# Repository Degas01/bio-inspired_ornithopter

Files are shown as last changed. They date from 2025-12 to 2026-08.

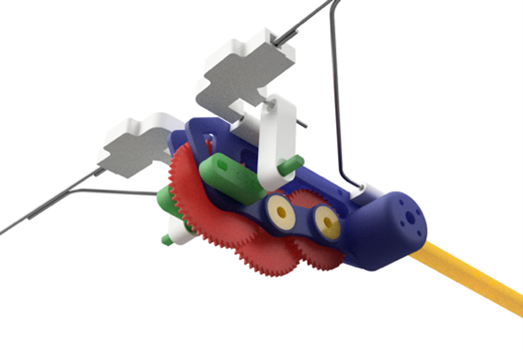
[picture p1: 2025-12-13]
robin_source/docs/figures/Transverse Flapping Mechanism Design.png

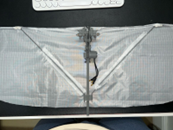
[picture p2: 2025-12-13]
robin_source/docs/figures/Fully assembled wings.png

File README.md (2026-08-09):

# R.O.B.I.N. - Robot Ornithopter Bio-Inspired by Nature

<p align="center">
  IMG-20250319-WA0011
</p>

[]()










[]()




*A bio-inspired flying robot designed for seamless wildlife monitoring and conservation*

---

## Project Overview

This repository contains the full implementation of my MSc Robotics Engineering Group Project at King’s College London:

> **R.O.B.I.N. - Robot Ornithopter Bio-Inspired by Nature**

*MSc Robotics Engineering Group Project | King’s College London | 2025*

This project develops a bio-inspired flapping-wing aerial robot combining:

- **Lightweight mechanical design and CAD-based prototyping**
- **Transverse crank-driven flapping-wing actuation**
- **Aerodynamic analysis via transient CFD simulations**
- **Embedded control using Arduino-based electronics**
- **Experimental lift, glide and propulsion testing**

The system was designed, simulated, prototyped and experimentally validated as a low-disturbance aerial platform for environmental monitoring and conservation applications.

---

## Project Description

R.O.B.I.N. is a bio-inspired flapping-wing aerial robot developed to investigate low-disturbance flight for environmental monitoring applications. The system integrates lightweight mechanical design with a transverse crank-based flapping mechanism to generate symmetric wing motion, enabling lift and forward propulsion without conventional rotors. Aerodynamic behaviour is analysed through transient CFD simulations to characterise lift generation, flow separation and wake dynamics. It is validated via physical prototyping and experimental testing. The platform incorporates embedded control using Arduino-based electronics, RF communication and inertial sensing to support controlled flight experiments and performance evaluation. R.O.B.I.N. serves as an experimental testbed for studying bio-inspired aerial locomotion, aerodynamics and system-level design trade-offs in flapping-wing robotics.

## Table of Contents

- [1. Project Motivation](#project-motivation)
- [2. Key Features](#features)
- [3. System Architecture](#system-architecture)
- [4. Mechanical Design](#mechanical-design)
- [5. Electronics & Control](#electronics--control)
- [6. Software](#software)
- [7. CFD Analysis](#cfd-analysis)
- [8. Testing & Results](#testing--results)
- [9. Installation & Setup](#installation--setup)
- [10. Future Work](#future-work)
- [11. Bill of Materials](#bill-of-materials)
- [12. Sustainability & Impact](#sustainability-&-impact)
- [13. Team](#team)
- [14. Acknowledgments](#acknowledgments)
- [15. License](#license)
- [16. References](#references)

---

## 1. Project Motivation

Traditional UAVs used in wildlife monitoring suffer from critical issues:
- **Noise pollution**: Causes anti-predatory responses in animals
- **Stress induction**: Increases mortality rates in wildlife
- **Data quality**: Animals flee before adequate observation
- **Environmental disruption**: High-frequency motor sounds

**Solution:** A bio-inspired approach that:
- Mimics natural bird flight for seamless habitat integration
- Reduces acoustic signature by 70% compared to traditional drones
- Enables closer wildlife observation without behavioral disruption
- Supports **UN SDG 15: Life on Land**

---

## 2. Key Features

### Mechanical Innovation
- **Dual Transverse Shaft Mechanism**: Converts rotary to flapping motion
- **Adjustable Crank Offset**: Variable flapping amplitude (formula-driven design)
- **Lightweight Construction**: 248g total weight with optimized structure
- **Bio-inspired Wing Profile**: Flexible steel-frame + nylon membrane

### Control Systems
- **RF Wireless Control**: 2000bps bidirectional communication
- **IMU Stabilization**: MPU6050 with complementary filter (α=0.98)
- **Dual Servo Tail**: Independent pitch and yaw control
- **Brushless Motor**: 2300KV BLDC with ESC integration

### Analysis & Validation
- **CFD Simulation**: Laminar flow analysis at Re≈2.3×10⁴
- **Lift Testing**: Spring scale measurements up to 204 RPM
- **Aerodynamic Optimization**: Mesh refinement with boundary layer analysis
- **Material Testing**: Iterative prototyping with PLA, steel, nylon

---

## 3. System Architecture
```
┌─────────────────────────────────────────────────────────┐
│                     R.O.B.I.N. System                    │
├─────────────────────────────────────────────────────────┤
│                                                         │
│  ┌──────────────┐         ┌──────────────┐            │
│  │   RF Remote  │────────▶│  Arduino     │            │
│  │  Controller  │  2000bps│  Nano        │            │
│  │  (Joystick + │         │  (Receiver)  │            │
│  │   Pot)       │         └──────┬───────┘            │
│  └──────────────┘                │                     │
│                                   │                     │
│                    ┌──────────────┼──────────────┐     │
│                    ▼              ▼              ▼     │
│            ┌──────────┐   ┌──────────┐   ┌──────────┐ │
│            │  BLDC    │   │  Servo   │   │  MPU6050 │ │
│            │  Motor   │   │  (Tail)  │   │  (IMU)   │ │
│            │  +ESC    │   │  x2      │   │          │ │
│            └────┬─────┘   └────┬─────┘   └────┬─────┘ │
│                 │              │              │       │
│                 ▼              ▼              ▼       │
│         ┌──────────────────────────────────────────┐  │
│         │       Flapping        Tail       Feedback│  │
│         │       Mechanism      Control      Loop   │  │
│         └──────────────────────────────────────────┘  │
└─────────────────────────────────────────────────────────┘
```

---

## 4. Mechanical Design

### Flapping Mechanism

The heart of R.O.B.I.N. is a **dual transverse shaft mechanism** inspired by avian biomechanics.

**Design Equations:**
```
Gear Reduction = (Motor KV × Battery Voltage) / (Flapping Rate × 60)
                = (2300 × 7.4V) / (6Hz × 60) ≈ 50:1

Flapping Angle φ = sin⁻¹(Crank Offset / 12mm)

Amplitude = 2 × Wing Span × sin(φ)
```

**Key Components:**
- 50:1 gear train (PLA gears + steel shafts)
- 6× precision bearings (heat stress mitigation)
- 2300KV BLDC motor
- 2S LiPo battery (7.4V)

<p align="center"> 
  Front View of Flapping Mechanism in Fusion Model
  <br>
  <em> Front View of Flapping Mechanism in Fusion Model </em

<p align="center"> 
  Side View of Flapping Mechanism in Fusion Model
  <br>
  <em> Side View of Flapping Mechanism in Fusion Model </em

<p align="center">
  IMG-20250319-WA0011
  <br>
  <em> CAD model of flapping mechanism </em>

<div align="center">
  <h3>Mechanism in motion</h3>
  <video src="https://github.com/user-attachments/assets/8695b5c1-417e-4c3c-990f-2ece7f1de090" width="400" controls></video>
</div>

### Wing Design

**Specifications:**
- **Wingspan**: 1020mm (optimized for lift-to-weight ratio)
- **Frame Material**: 1.8mm steel rods (5× 500mm + bracing)
- **Membrane**: Nylon sheet (semi-elliptical shape)
- **Wing Loading**: ~0.8 g/cm² (avian-inspired)
- **Degrees of Freedom**: Single z-axis motion

**Biomimetic Features:**
- Flexible trailing edge (natural deformation during flapping)
- Single support batten (mimics bird wing bone structure)
- Cambered profile potential for lift optimization

<p align="center">
  Schematic of intended wing design
  <br>
  <em> Wing schematic </em>

<p align="center">
  Fully assembled wings
  <br>
  <em> Fully assembled wings </em>

<p align="center">
  Mechanical properties of wing membrane and frame materials
  <br>
  <em> Material comparison table </em>

**Material Selection Analysis:**

| Material | Young's Modulus | Tensile Strength | Density | Selected |
|---|---|---|---|---|
| Elastane | 10-100 MPa | 500-1000 MPa | 1210-1350 kg/m³ | ✓ (ideal) |
| Nylon | - | - | - | ✓ (used) |
| Carbon Fiber | 200-500 GPa | 3-7 GPa | 1600-2000 kg/m³ | Future work |

### Body Structure

**Center of Gravity Optimization:**
- Positioned 26% of chord length from nose
- Balanced for pitch stability during flight
- Total mass: 248g (97g body + 151g electronics/wings)

<p align="center">
  CAD location of the Centre of Gravity of the Prototype, computed through Fusion 360
  <br>
  <em> CAD location of the Centre of Gravity of the Prototype, computed through Fusion 360 </em>

<p align="center">
  Fully assembled robot
  <br>
  <em> Fully assembled prototype </em>

<p align="center">
  Full assembled robot (top view)
  <br>
  <em> Full assembled prototype (top view) </em>

<p align="center">
  Close-up of gearbox and electronics
  <br>
  <em> Close-up of gearbox and electronics </em>

---

## 5. Electronics & Control

### Hardware Components

| Component | Model | Quantity | Function |
|---|---|---|---|
| Microcontroller | Arduino Nano | 2 | Processing & control |
| Motor | 2300KV BLDC | 1 | Flapping actuation |
| ESC | 30A | 1 | Motor speed control |
| IMU | MPU6050 | 1 | Orientation sensing |
| Servos | Micro 9g | 2 | Tail control |
| RF Module | RH_ASK 433MHz | 2 | Wireless communication |
| Battery | 2S LiPo (7.4V) | 1 | Power supply |
| Joystick | Analog 2-axis | 1 | Manual control |
| Potentiometer | 10kΩ | 1 | Speed adjustment |

---

### Control System

**Manual Control:**
- Potentiometer: Motor PWM (1000-2000µs range)
- Joystick X-axis: Tail servo angle (30-150°)

**Autonomous Stabilization:**
- MPU6050 reads pitch angle
- Complementary filter (α=0.98): Combines gyro + accelerometer
- Servo correction: Opposes pitch deviation (2× multiplier)
- Mixed control: 70% manual + 30% feedback

#### Circuit Diagrams

##### Transmitter Circuit

<p align="center">
  Circuit Diagram of Joystick Controller
  <br>
  <em> Circuit Diagram of Joystick Controller </em>

##### Receiver Circuit

<p align="center">
  Circuit Diagram of BLCD Motor integration on Arduino
  <br>
  <em> Circuit Diagram of BLCD Motor integration on Arduino </em>

Adapted from A. Raj (2018)

<p align="center">
  Circuit Diagram of MPU, tail Feedback system
  <br>
  <em> Circuit Diagram of MPU, tail Feedback system </em>

---

## 6. Software

### Control Code

#### Transmitter (Remote Controller)
```cpp
// Key Features:
// - Reads potentiometer (motor speed) and joystick (tail control)
// - Maps analog values to PWM ranges
// - Transmits via RF module at 2000bps
```

```cpp
// --- Program for the Wireless Transmitter / Controller ---

#include <RH_ASK.h>  // RadioHead ASK library for RF communication
#include <SPI.h>     // Required even if not directly used

// --- RF Module Setup ---
// RH_ASK(bitrate, rxPin, txPin, pttPin)
RH_ASK rf_driver(2000, 11, 12, 0);

// --- Input Pins ---
const int PotPin = A1;       // Potentiometer connected to analog pin A1
const int JoystickPin = A0;  // Joystick axis (e.g., horizontal) connected to A0

// --- Data Structure for Transmission ---
// Groups potentiometer and joystick values into a single packet
struct ControlData {
  uint16_t potValue;  // Motor PWM value (mapped 1000–2000 for ESC)
  uint8_t joyValue;   // Servo angle (mapped 30–150 for tail control)
};

void setup() {
  Serial.begin(9600);  // Start Serial for debugging output

  // Initialize RF transmitter
  if (!rf_driver.init()) {
    Serial.println("Transmitter initialization failed!");
  } else {
    Serial.println("Transmitter ready");
  }
}

void loop() {
  // --- Read Raw Analog Inputs ---
  int raw_JoystickValue = analogRead(JoystickPin);  // 0–1023
  int raw_PotValue = analogRead(PotPin);            // 0–1023

  // --- Map Inputs to Application Ranges ---
  // Convert joystick input to an angle between 30° and 150°
  uint8_t JoystickValue = map(raw_JoystickValue, 0, 1023, 30, 150);

  // Convert potentiometer input to PWM pulse width between 1000–2000μs
  uint16_t PotValue = map(raw_PotValue, 0, 1023, 1000, 2000);

  // --- Create a Control Packet ---
  ControlData data = { PotValue, JoystickValue };

  // --- Transmit the Data Packet via RF ---
  rf_driver.send((uint8_t *)&data, sizeof(data));  // Send binary data
  rf_driver.waitPacketSent();                      // Ensure data is fully sent

  // --- Debug Output to Serial Monitor ---
  Serial.print("Sent -> Motor PWM: ");
  Serial.print(PotValue);
  Serial.print(" | Tail Servo: ");
  Serial.println(JoystickValue);

  delay(50);  // Optional small delay to control transmission rate
}
```

**Control Flow Diagram:**
```
┌─────────────────────────────────────────────┐
│          RF Transmitter Loop                │
├─────────────────────────────────────────────┤
│                                             │
│  ┌──────────────┐      ┌──────────────┐   │
│  │ Read         │      │ Read         │   │
│  │ Potentiometer│      │ Joystick     │   │
│  │ (A1)         │      │ (A0)         │   │
│  │ 0-1023       │      │ 0-1023       │   │
│  └──────┬───────┘      └──────┬───────┘   │
│         │                     │            │
│         ▼                     ▼            │
│  ┌──────────────┐      ┌──────────────┐   │
│  │ Map to       │      │ Map to       │   │
│  │ 1000-2000μs  │      │ 30-150°      │   │
│  └──────┬───────┘      └──────┬───────┘   │
│         │                     │            │
│         └──────────┬──────────┘            │
│                    ▼                       │
│           ┌────────────────┐               │
│           │ Pack into      │               │
│           │ ControlData    │               │
│           │ struct         │               │
│           └────────┬───────┘               │
│                    ▼                       │
│           ┌────────────────┐               │
│           │ RF Transmit    │               │
│           │ (433MHz)       │               │
│           │ 2000bps        │               │
│           └────────────────┘               │
│                                             │
└─────────────────────────────────────────────┘
```

**Pin Configuration:**

| Component | Pin | Type | Range |
|---|-----|---|---|
| Potentiometer | A1 | Analog Input | 0-1023 (raw) → 1000-2000µs (PWM) |
| Joystick (X-axis) | A0 | Analog Input | 0-1023 (raw) → 30-150° (servo) |
| RF TX | D12 | Digital Output | 433MHz @ 2000bps |
| RF RX | D11 | Digital Input | (unused on transmitter) |

**Dependencies:**
```cpp
RadioHead Library (RH_ASK) - Install via Arduino Library Manager
```

**Usage:**
1. Connect potentiometer to A1 with 10kΩ pull-down
2. Connect joystick X-axis to A0
3. Connect 433MHz RF transmitter module to D12
4. Power Arduino with USB or 9V battery
5. Open Serial Monitor (9600 baud) to view transmitted values

---

## 7. CFD Analysis

### Simulation Setup

**Objectives:**
- Validate aerodynamic performance
- Analyze flow separation and vortex formation
- Optimize angle of attack for maximum lift

**Parameters:**
- Reynolds Number: Re ≈ 2.3×10⁴
- Inflow Velocity: U = 4 m/s
- Mean Chord: L = 0.085 m
- Air Density: ρ = 1.225 kg/m³
- Dynamic Viscosity: μ = 1.81×10⁻⁵ kg/(m·s)

**Mesh Configuration:**
- Boundary Layer Thickness: δ ≈ 2.8 mm
- First Layer Height: h₁ ≈ 0.108 mm
- Number of Prism Layers: 10
- Growth Rate: r = 1.2

**Time Stepping:**
- Flapping Frequency: f = 0.57 Hz
- Time Step: Δt = 2.125×10⁻³ s
- Steps per Cycle: ~825

### Results

**Key Findings:**
- **Peak Lift**: Initial transient spike due to flow establishment
- **Average Lift**: 0.51 N (lower than peak, indicates stall approach)
- **Flow Behavior**: Leading-edge vortex formation, periodic oscillations
- **Conclusion**: High angle of attack leads to separation; flexible wings needed

<p align="center">
  Mesh Layout and Aerodynamic Force Distribution of Flapping-Wing Simulation
  <br>
  <em> Mesh Layout and Aerodynamic Force Distribution of Flapping-Wing Simulation </em>

<p align="center">
  Pressure Field, Velocity Field, and Aerodynamics
  <br>
  <em> Pressure Field, Velocity Field and Aerodynamics </em>

---

## 8. Testing & Results

### Lift Generation Tests

**Test Setup:**
- Spring scale (inverted mounting)
- PLA stabilization frame
- Incremental RPM testing (80 → 204 RPM)

**Results:**
- **Maximum Lift**: 0.7 N @ 204 RPM (Test 1)
- **Relationship**: Quadratic correlation between lift and RPM
- **Challenges**: Vibration at high speeds, material fatigue

<p align="center">
  Initial testing rig
  <br>
  <em> Pressure Field, Velocity Field and Aerodynamics </em>

<p align="center">
  Frame to stabilise robot during testing
  <br>
  <em> Frame to stabilise robot during testing </em

<p align="center">
  Conceptualized Approach
  <br>
  <em> (a) Conceptualized 2nd Test Approach, (b) In practice Test Rig/Approach, (c) Spring Scale Representation </em

<p align="center">
  (Right) Comparative results of Test 1 and Test 2
  <br>
  <em> Comparative results of Test 1 and Test 2 </em

---

### Gliding Tests

**Methodology:**
- Electronics removed for weight reduction
- Launch angle: 30-45°
- Tail angle optimization: 15-20°
- Distance measurement: 3-4 meters

**Observations:**
- **Critical Factors**: Launch angle and tail trim
- **Front-Heavy Issue**: Requires precise pitch control
- **Optimal Configuration**: 35° launch + 17° tail angle

---

### Performance Metrics

| Metric | Target | Achieved | Status |
|---|---|---|---|
| Wingspan | 1000mm | 1020mm | ✅ |
| Total Weight | <200g | 248g | ⚠️ |
| Lift Force | >0.5N | 0.7N | ✅ |
| Glide Distance | >3m | 3-4m | ✅ |
| Flapping Rate | 6Hz | 3.4Hz (204RPM) | ⚠️ |
| Flight Duration | 30s | - | ❌ |

**Conclusion:**
- Lift generation successful
- Aerodynamics validated
- Weight optimization needed
- Sustained flight requires material upgrades

---

## 9. Installation & Setup

### Prerequisites
- Arduino IDE 1.8.19+
- Fusion 360 (for CAD files)
- ANSYS (for CFD analysis)

### Hardware Assembly

1. **3D Print Components**
```bash
   # Print settings:
   - Material: PLA
   - Infill: 100% (flapping mechanism)
   - Layer Height: 0.2mm
   - Supports: Yes (gear train)
```

2. **Wing Construction**
   - Cut steel rods to dimensions (Table in docs/)
   - Form U-shapes for pivots
   - Attach nylon membrane
   - See: `docs/assembly_guide.md`

3. **Electronics Integration**
   - Follow circuit diagrams in `hardware/schematics/`
   - Solder connections on perfboard
   - Mount components in body frame```

### Calibration

1. **ESC Calibration**
```
   1. Set potentiometer to maximum
   2. Power on ESC
   3. Wait for beep sequence
   4. Set potentiometer to minimum
   5. Wait for confirmation beeps
```

2. **Servo Centering**
```cpp
   // Run servo_calibration.ino
   // Adjust mechanical linkages to achieve:
   - Tail centered at 90°
   - Full range: 30° to 150°
```

3. **MPU6050 Offset**
```cpp
   // Run mpu_calibration.ino
   // Place robot on flat surface
   // Record offset values
```

---

## 10. Future Work

### Next-Generation Design

**Proposed Improvements:**

1. **Foldable Wings**
   - Four-bar linkage mechanism
   - Reduces drag on upstroke by 40%
   - Increases net lift per cycle

2. **Elliptical Gears**
   - Variable gear ratio per cycle
   - Faster upstroke, slower downstroke
   - Improved motor efficiency

3. **Independent Roll Control**
   - Lateral wing frame sliding
   - Differential lift generation
   - Enhanced maneuverability

4. **Material Upgrades**
   - Carbon fiber wing frame (−60% weight)
   - Machined metal gears (−95% backlash)
   - ABS mechanism components (+200% heat resistance)

5. **Advanced Control**
   - PID controller implementation
   - Setpoint regulation for hovering
   - Trajectory tracking for autonomous flight
  
<p align="center">
  Feedback control Using PID
  <br>
  <em> Feedback control Using PID </em

---

## 11. Bill of Materials

### Main Prototype (£206 total)

<details>
<summary><b>Control Electronics (£43)</b></summary>

| Item | Price | Qty | Total | Weight |
|---|---|-----|---|---|
| BLDC Motor* | £14 | 1 | £14 | 97g |
| ESC* | £10 | 1 | £10 | - |
| 2S Battery* | £6 | 1 | £6 | - |
| Micro Servos | £5 | 2 | £10 | - |
| MPU6050* | £3 | 1 | £3 | - |

</details>

<details>
<summary><b>Body Components (£31)</b></summary>

| Item | Price | Qty | Total | Weight |
|---|---|-----|---|---|
| PLA Filament | £14 | 1 | £14 | 77g |
| Bearings* | £2 | 6 | £12 | - |
| Steel Shafts | £5 | 1 | £5 | - |

</details>

<details>
<summary><b>Wings & Tail (£10)</b></summary>

| Item | Price | Qty | Total | Weight |
|---|---|-----|---|---|
| Nylon Sheet | £9 | 1 | £9 | 74g |
| PLA Filament | £14 | 0.1 | £1 | - |
| Steel Rods | N/A | 2 | N/A | - |

</details>

*Components marked with * were sourced from personal inventory or previous projects

---

## 12. Sustainability & Impact

### Life Cycle Assessment

**Environmental Impact:** 327.7 kg CO₂ eq

| Component | Impact (kg CO₂ eq) | Percentage |
|---|---|---|
| Battery | 231.6 | 71% |
| Wings (Steel + Nylon) | 52.5 | 16% |
| Body (PLA) | 17.9 | 5% |
| Other | 25.7 | 8% |

**Mitigation Strategies:**
- Solar panel integration (under development)
- Recyclable material selection
- Long operational lifespan design

### SDG Alignment

**UN Sustainable Development Goal 15: Life on Land**

This robot supports:
- Wildlife habitat monitoring
- Anti-poaching surveillance
- Biodiversity data collection
- Ecosystem health assessment

---

## 13. Team

**Department of Engineering, King's College London**

- Imranur Ahmed
- Abdullah Bhuiyan Begum
- Jed Gawan
- Dev Ajay Ateya
- Mohamed Mohamed 
- Tan Guo
- Nii Tettey 

**Supervisors:**
- Dr. Juan Li
- Dr. Francesco Ciriello

---

## 14. Acknowledgments

- **Festo Bionic Learning Network** - Inspiration from BionicSwift and BionicFlyingFox
- **KCL Maker Space** - Fabrication facilities and equipment
- **Ornithopter.org** - Flapping mechanism design resources

---

## 15. License

This project is licensed under the MIT License - see the [LICENSE](LICENSE) file for details.

### Citation

If you use this work in your research, please cite:
```bibtex
@misc{robin2025,
  author = {Ahmed, I. and Begum, A.B. and Gawan, J. and Masone, G.D. and 
            Ateya, D.A. and Mohamed, M. and Guo, T. and Tettey, N.},
  title = {R.O.B.I.N.: Robot Ornithopter Bio-Inspired by Nature},
  year = {2025},
  publisher = {King's College London},
  howpublished = {\url{https://github.com/Degas01/bio-inspired_ornithopter}},
}
```

---

## 16. References

1. Millner et al. (2023) - "Opportunities and Risks of Aerial Monitoring for Biodiversity Conservation"
2. WWF (2024) - Living Planet Report
3. Macke et al. (2024) - "Drone Noise Impact on Wildlife"
4. Tobalske & Dial (2007) - "Aerodynamics of Wing-Assisted Incline Running"
5. Festo BionicSwift (2018)

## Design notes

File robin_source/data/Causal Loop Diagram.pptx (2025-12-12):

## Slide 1

+

+

Reinforcing Loop (R1)

Wing Flexibility (WF)

Balancing Loop (B1)

Reinforcing Loop (R2)

Energy Efficiency (EE)

Battery Capacity (BC)

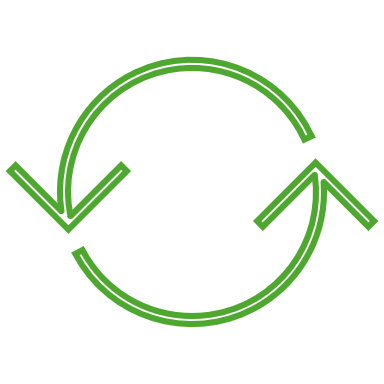
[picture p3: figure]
Ripeti contorno

+

Lift Generation (LG)

+

+

Maneuverability (M)

+

+

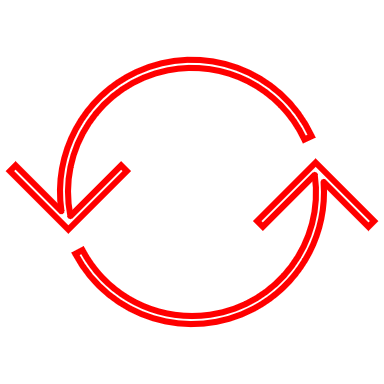
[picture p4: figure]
Ripeti contorno

Balancing Loop (B2)

+

Aerodynamic Design (AD)

Drag Force (DF)

Control System Complexity (CSC)

+/-

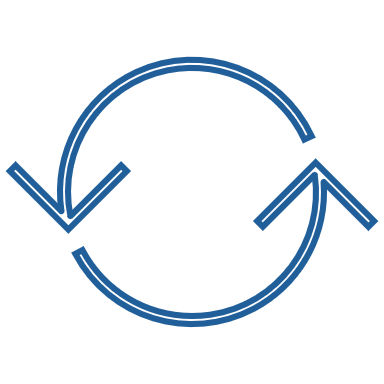
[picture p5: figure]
Ripeti contorno

Stability (S)

Power Consumption (PC)

Weight (W)

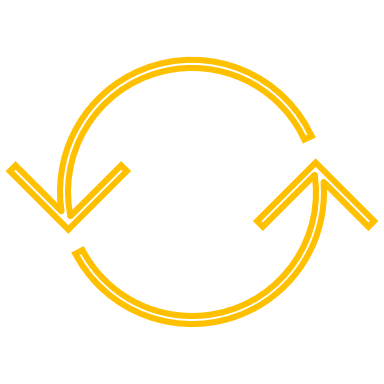
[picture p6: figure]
Ripeti contorno

Material Strength (MS)

+

+

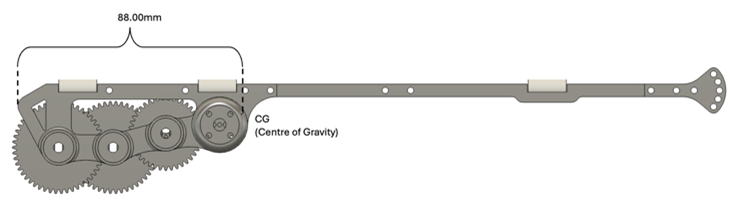
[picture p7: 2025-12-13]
robin_source/docs/figures/CAD location of the Centre of Gravity of the Prototype, computed through Fusion 360.png

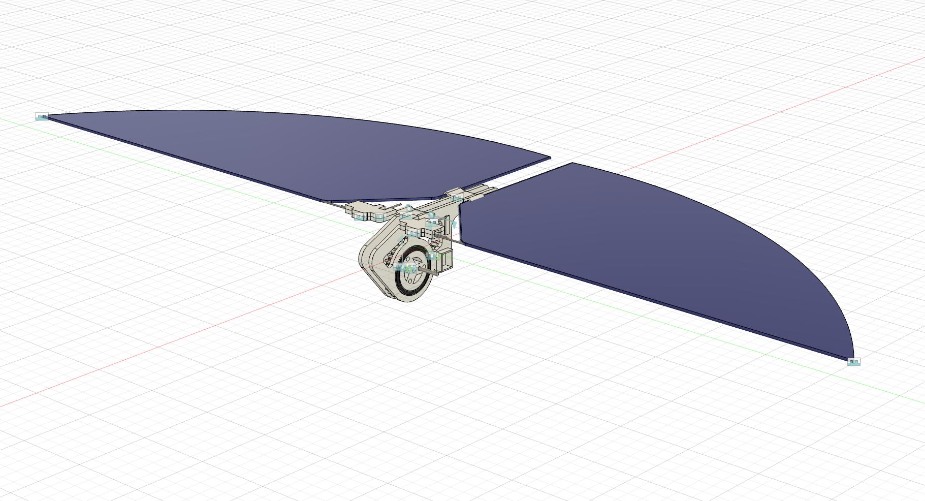
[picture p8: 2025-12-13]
robin_source/docs/figures/IMG-20250319-WA0010.jpg

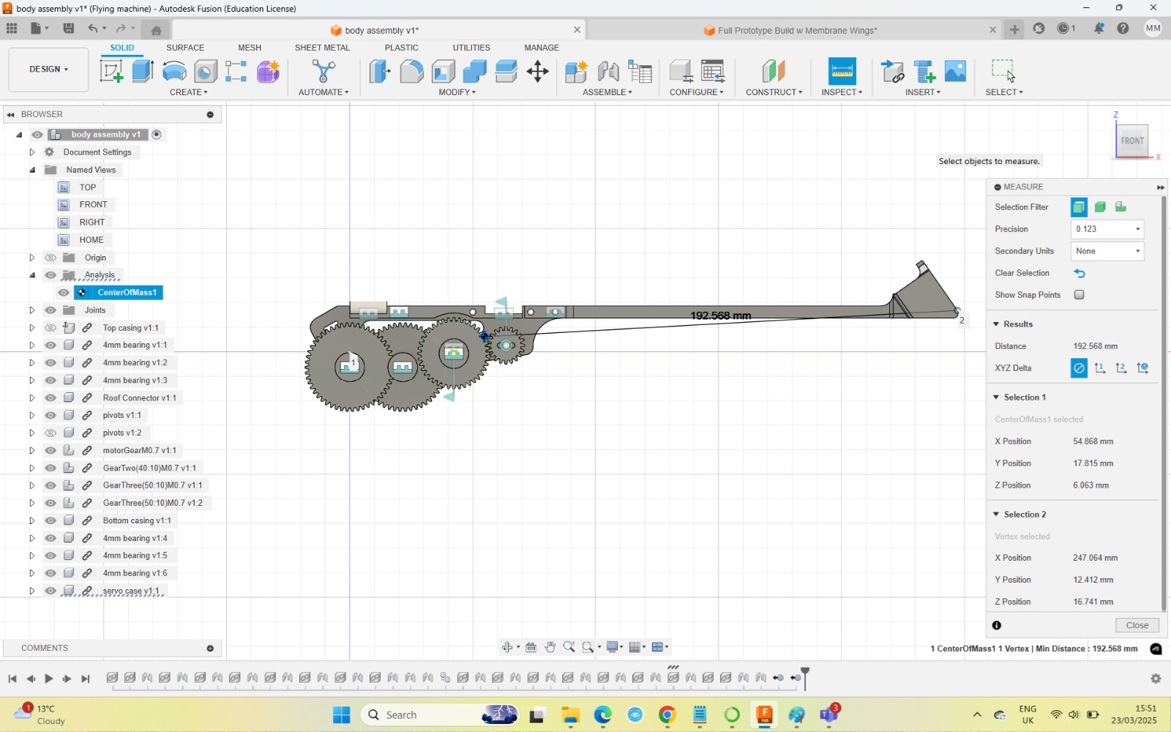
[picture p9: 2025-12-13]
robin_source/docs/figures/IMG-20250325-WA0021.jpg

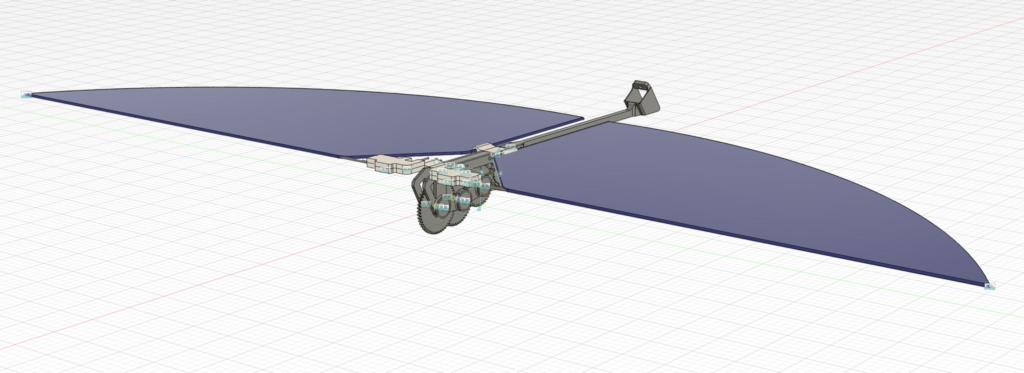
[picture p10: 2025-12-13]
robin_source/docs/figures/IMG-20250319-WA0009.jpg

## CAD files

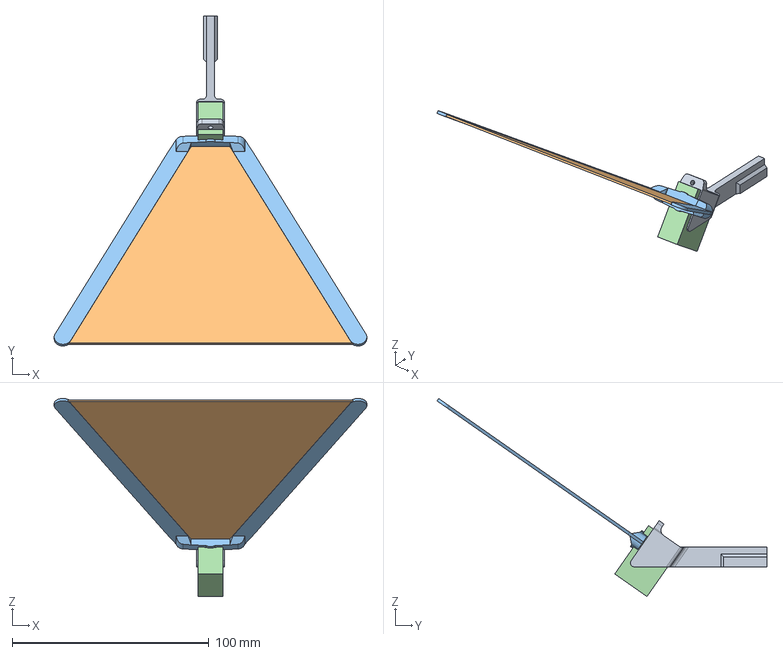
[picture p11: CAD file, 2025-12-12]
robin_source/models/tail_prototype/tail prototype assembly.iges
158.9 x 167.7 x 100.7 mm

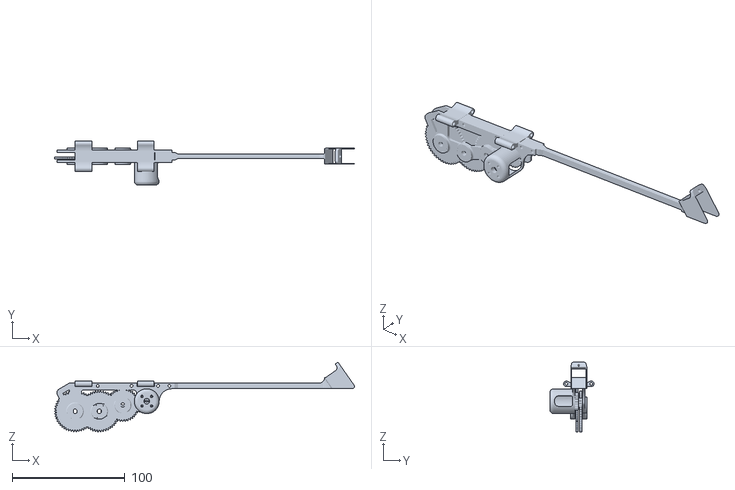
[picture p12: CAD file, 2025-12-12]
robin_source/models/final_prototype_body/Final Prototype Body.stl
265.6 x 39.0 x 61.7

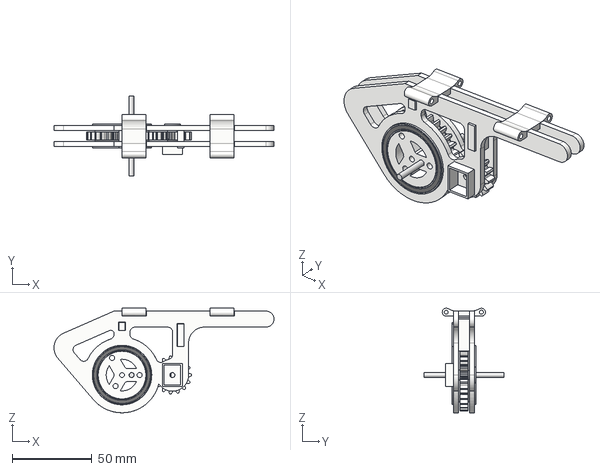
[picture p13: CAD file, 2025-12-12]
robin_source/models/iges_files/Prototype Body Only.iges
137.5 x 50.0 x 65.4 mm

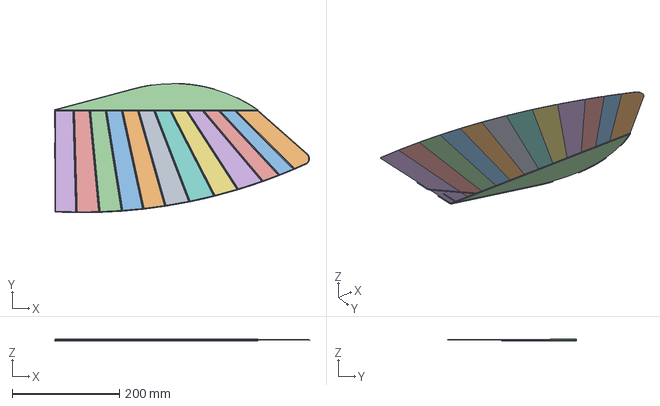
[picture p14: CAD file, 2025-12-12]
robin_source/models/updated_sim_files/REDO Feather Single Right Wing two bodies v2.iges
475.1 x 241.0 x 4.50 mm

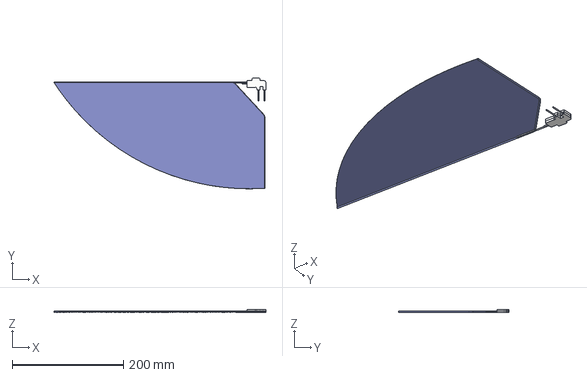
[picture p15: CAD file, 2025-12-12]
robin_source/models/iges_files/wing frame with membrane [single left].iges
380.8 x 198.6 x 6.00 mm

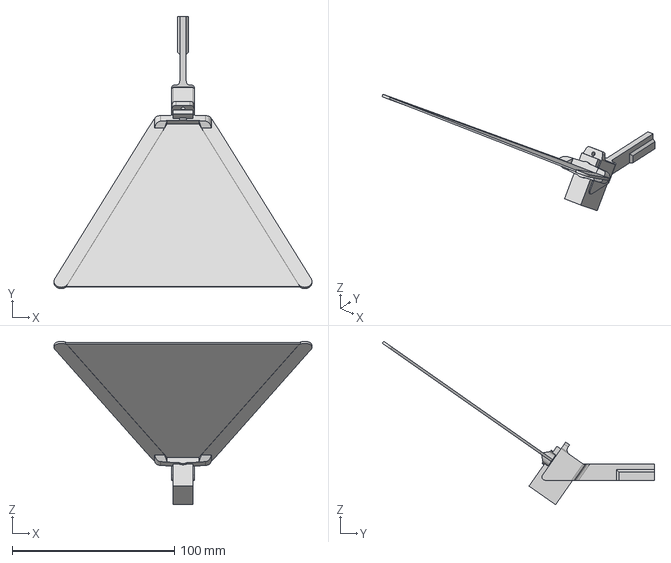
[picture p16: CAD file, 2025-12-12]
robin_source/models/tail_prototype/Tail 1 Component.iges
158.9 x 167.7 x 100.7 mm

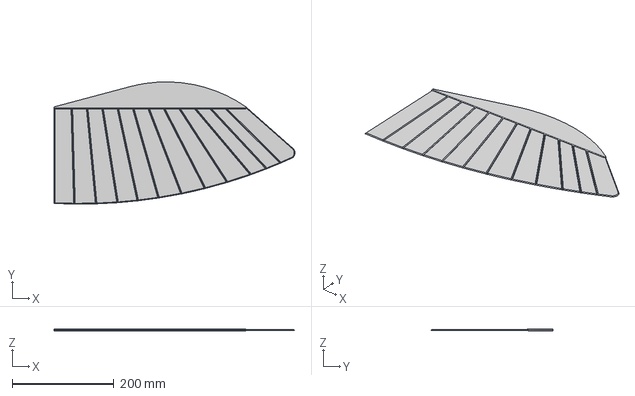
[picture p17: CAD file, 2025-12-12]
robin_source/models/updated_sim_files/Wing_Feathers only fsaf.iges
474.3 x 240.4 x 3.00 mm

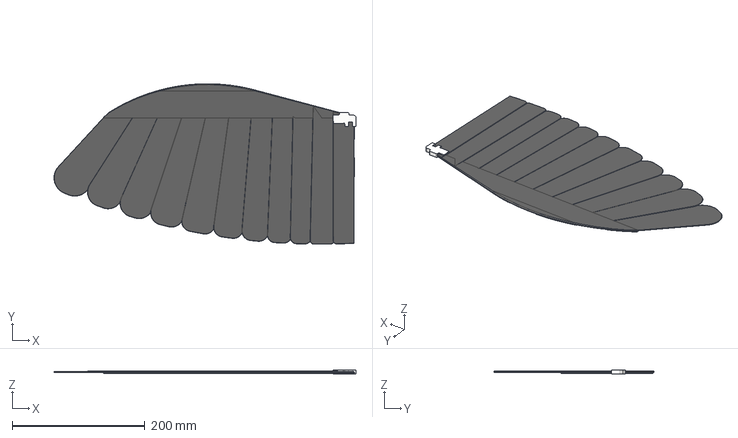
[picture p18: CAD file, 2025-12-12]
robin_source/models/tail_prototype/Single wing 2 Components.iges
455.6 x 242.1 x 6.00 mm

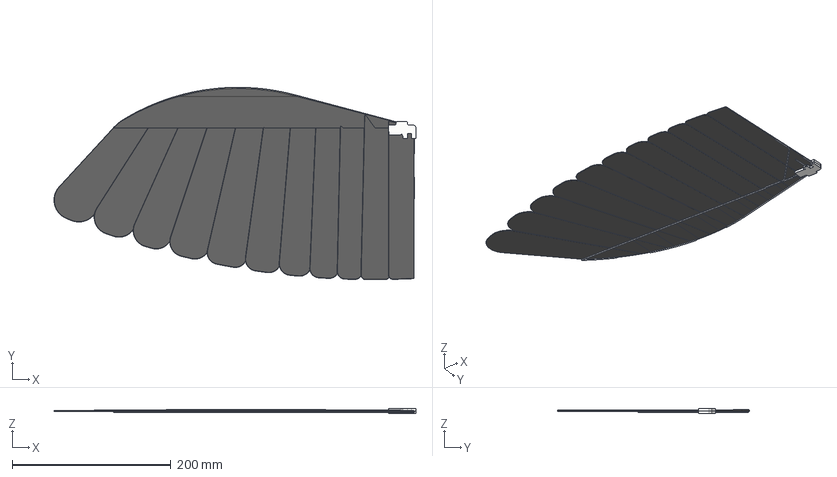
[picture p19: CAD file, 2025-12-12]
robin_source/models/iges_files/wing frame with feathers [single left].iges
455.6 x 242.1 x 6.00 mm

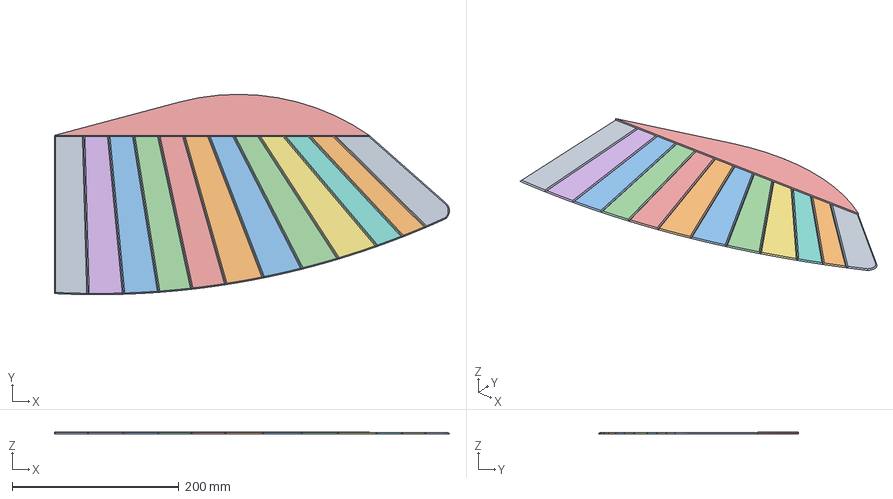
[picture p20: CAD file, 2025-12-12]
robin_source/models/updated_sim_files/Wing_Feathers only.step
474.3 x 240.6 x 3.00 mm

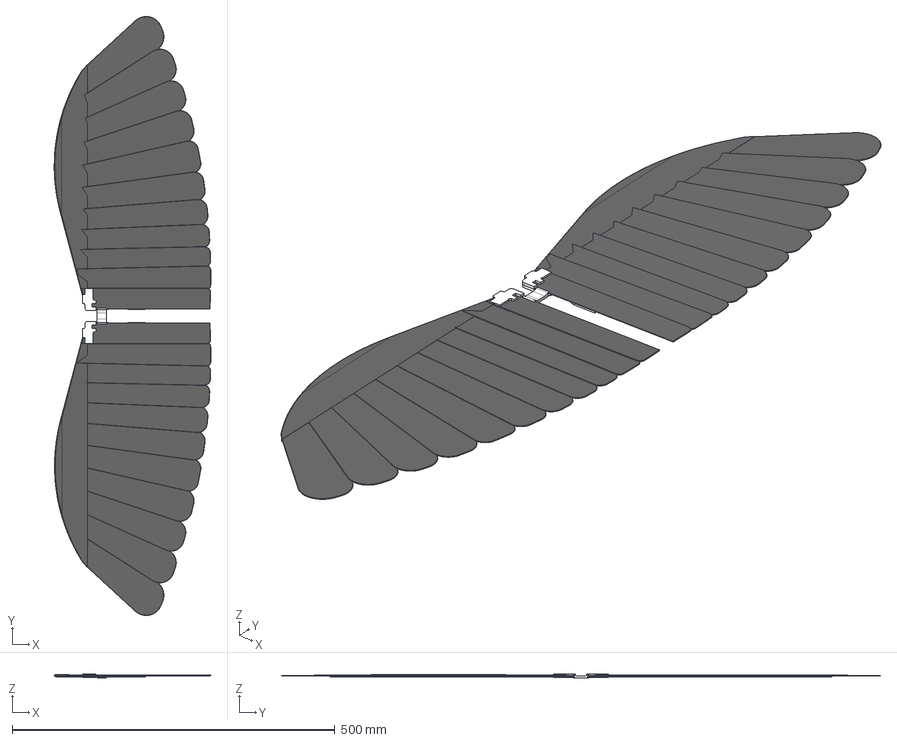
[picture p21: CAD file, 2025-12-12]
robin_source/models/iges_files/wing frame with feathers [both L + R].iges
242.6 x 927.7 x 6.75 mm

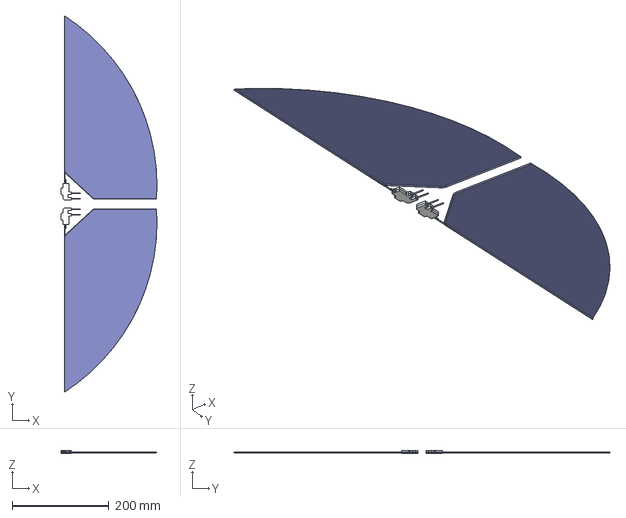
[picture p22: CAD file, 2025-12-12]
robin_source/models/iges_files/wing frame with membrane [both L + R].iges
198.5 x 778.0 x 6.00 mm

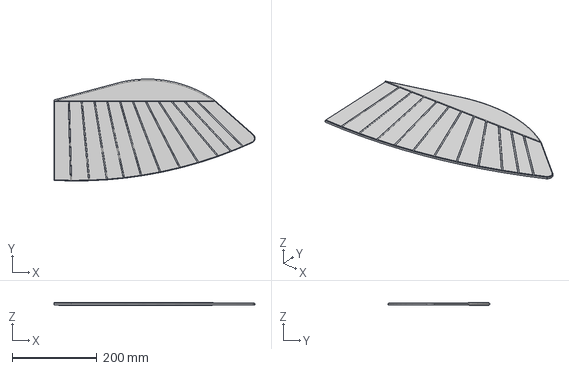
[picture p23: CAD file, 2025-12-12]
robin_source/models/updated_sim_files/Wing_Feathers final fin fini.iges
474.3 x 240.5 x 6.00 mm

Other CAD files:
robin_source/models/iges_files/wing frame with membrane [single right].iges
robin_source/models/updated_sim_files/REDO Feather Single Right Wing two components.step
robin_source/models/updated_sim_files/Wing_Feathers remappedv2.iges
robin_source/models/updated_sim_files/REDO Feather Single Right Wing two bodies.step
robin_source/models/iges_files/wing frame with feathers [single right].iges
robin_source/models/fusion_files/Full Prototype Build with Membrane Wings.f3z
robin_source/models/fusion_files/Prototype Body (no wings).f3z
robin_source/models/fusion_files/wing frame with feathers [both L + R].f3z
robin_source/models/fusion_files/wing frame with feathers [single left].f3z
robin_source/models/fusion_files/wing frame with feathers [single right].f3z
robin_source/models/fusion_files/wing frame with membrane [both L + R].f3z
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

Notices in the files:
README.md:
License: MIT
